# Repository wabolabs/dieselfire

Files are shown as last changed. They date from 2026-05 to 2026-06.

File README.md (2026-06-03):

# DieselFire

> **⚠ ALPHA QUALITY — NOT TESTED ON HARDWARE**
>
> This project is in early development. The firmware has **not** been tested on
> physical ESP32-S3 hardware. All protocol simulation and UI development has
> been done via the **PC simulator**. There are likely bugs, edge cases, and
> incomplete drivers. Use at your own risk. Hardware bringup is in progress.

A modernized open-source controller for generic Chinese diesel heaters, forked from [Afterburner](https://gitlab.com/mrjones.id.au/bluetoothheater) by Ray Jones.

## Overview

DieselFire is a complete redesign of the Afterburner project, updated with modern hardware while preserving the core functionality that made Afterburner popular:

- **Diesel heater control** via the "blue wire" half-duplex serial protocol (25000 baud)
- **WiFi connectivity** for web interface, MQTT, and OTA updates
- **Bluetooth Low Energy** for mobile app control
- **Environmental monitoring** with temperature, humidity, pressure, and CO detection
- **Color touchscreen UI** with LVGL graphics
- **Programmable timers** (14 channels)
- **Fuel gauge** and hour meter
- **Smart error detection**

## Online Simulator

Try the DieselFire UI in your browser without any hardware:
**[dieselfire.wabo.cc](https://dieselfire.wabo.cc)**

Runs as a WebAssembly build of the native PC simulator. Includes the full
touchscreen interface, Blue Wire protocol simulation, and a diesel heater
emulator for testing all states and fault conditions.

## Hardware

| Component | Specification |
|---|---|
| **MCU** | ESP32-S3-WROOM-1-N8R8 (8MB flash, 8MB PSRAM) |
| **Display** | 2.8" 320×240 ILI9341 TFT with capacitive touch (GT911) |
| **Ambient Sensor** | BME280 (temperature, humidity, pressure/altitude) |
| **CO Sensor** | MQ-7 carbon monoxide (external module) |
| **RTC** | DS3231 with CR2032 battery backup |
| **External Temp** | DS18B20 waterproof probe (optional) |
| **Power** | 12V DC input (heater system voltage) |
| **Connectivity** | USB-C (programming/debug), WiFi, BLE 5 |
| **Expansion** | 2× 2×10 GPIO headers |

## License

DieselFire is released under the **GNU General Public License v3.0**.

This project is a **fork** of [Afterburner](https://gitlab.com/mrjones.id.au/bluetoothheater) by Ray Jones (Copyright 2018-2020). The original Afterburner code was used as the foundation and has been substantially modified and modernized. All original Afterburner code remains under GPLv3 as per the original license.

See [LICENSE](LICENSE) for the full license text.

## Quick Start

1. **Hardware**: Order PCB from JLCPCB/PCBWay using Gerber files in `gerber/`
2. **Firmware**: Install PlatformIO, then run `pio run` to build
3. **Flash**: Connect via USB-C and run `pio run --target upload`
4. **Configure**: Connect to the AP "DieselFire" (password: thereisnospoon) or connect to existing WiFi

## Project Structure

```
DieselFire/
├── boards/                  # PlatformIO board definitions
├── docs/
│   ├── design/              # Design documents and specifications
│   ├── firmware/            # Firmware documentation
│   └── hardware/            # Hardware documentation
├── gerber/                  # PCB fabrication files
├── kicad/
│   ├── schematic/           # KiCad schematic files
│   ├── pcb/                 # KiCad PCB layout files
│   ├── footprints/          # Custom KiCad footprints
│   └── libraries/           # KiCad symbol libraries
├── lib/                     # PlatformIO libraries (vendored)
├── src/
│   ├── cfg/                 # Configuration headers
│   ├── Display/             # LVGL display driver and screens
│   ├── Protocol/            # Blue wire protocol handling
│   ├── RTC/                 # Real-time clock and timers
│   ├── Utility/             # Utility classes (sensors, storage, etc.)
│   ├── WiFi/                # WiFi, web server, OTA
│   ├── Bluetooth/           # BLE implementation
│   └── OLED/                # Legacy OLED code (to be removed)
├── platformio.ini           # PlatformIO project configuration
├── README.md
└── LICENSE
```

## Features

### Heater Control
- Power on/off commands
- Temperature setpoint adjustment
- Fuel mixture tuning
- Pump priming
- Thermostat mode (cyclic, stop/start, linear)
- Frost protection mode
- Humidity-based control
- OEM controller co-existence mode

### Connectivity
- **WiFi**: STA mode (connect to existing network) or AP mode (captive portal)
- **BLE 5**: Bluetooth Low Energy for mobile app control
- **MQTT**: Publish heater status and receive commands
- **Web Server**: HTTPS web interface with WebSocket JSON streaming
- **OTA**: Over-the-air firmware updates

### Sensors
- **BME280**: Ambient temperature, humidity, pressure (altitude)
- **MQ-7**: Carbon monoxide detection (external module)
- **DS18B20**: External waterproof temperature probe (optional)
- **SCD41**: CO2 sensing (optional, not on default board)

### User Interface
- **2.8" Color Touchscreen**: 320×240 ILI9341 with capacitive touch
- **LVGL Graphics**: Hardware-accelerated UI with PSRAM buffer
- **Menu System**: Hierarchical menus for all settings
- **Timer Chart**: Visual overview of 14 programmable timers
- **Status Display**: Real-time heater status, sensor readings, alerts

### Safety
- **CO Detection**: MQ-7 sensor with alarm LED
- **Low Voltage Cutout**: Auto-shutdown when battery voltage is too low
- **Error Detection**: Smart monitoring of heater state transitions
- **Watchdog**: Hardware and software watchdog for reliability

## Pinout

### ESP32-S3 GPIO Mapping

| Peripheral | GPIO | Interface | Notes |
|---|---|---|---|
| **Native USB** | IO19 (DP) / IO20 (DN) | USB 1.1 | USB-C, programming + debug |
| **SPI Display** | IO18 (MOSI) / IO17 (SCK) / IO16 (MISO) | SPI (HSPI) | ILI9341, 320×240 |
| **Display CS** | IO15 | GPIO | TFT chip select |
| **Display DC** | IO14 | GPIO | TFT data/command |
| **Display RST** | IO13 | GPIO | TFT reset |
| **Display BL** | IO12 | GPIO/PWM | TFT backlight |
| **Touch I2C** | IO21 (SDA) / IO10 (SCL) | I2C (GPIO) | GT911 capacitive touch |
| **Touch INT** | IO9 | GPIO | Touch interrupt |
| **Touch RST** | IO8 | GPIO | Touch reset |
| **Blue Wire UART** | IO43 (TX) / IO44 (RX) | UART0 @ 25kbps | Heater communication |
| **Tx Gate** | IO47 | GPIO | 74LCX125 control |
| **BME280 I2C** | IO21 (SDA) / IO22 (SCL) | I2C (VSPI) | Temp/RH/Pressure |
| **DS3231 I2C** | IO21 (SDA) / IO22 (SCL) | I2C (VSPI) | RTC |
| **DS18B20** | IO45 | OneWire | External temp probe |
| **MQ-7 AOUT** | IO4 | ADC1 (12-bit) | CO analog reading |
| **MQ-7 DOUT** | IO5 | GPIO input | CO digital alert |
| **Status LED** | IO48 | GPIO | Green, active-low |
| **CO Alarm LED** | IO44 | GPIO | Red, active-low |
| **Power Button** | IO0 | GPIO (input) | With pull-up |
| **Reset Button** | IO5 | GPIO | Standard boot button |

### Expansion Headers

**H1 (2×10):** GPIO33, GPIO34, GPIO35, GPIO36, GPIO37, GPIO38, GPIO39, GPIO40, 3.3V, GND, GND
**H2 (2×10):** GPIO41, GPIO42, GPIO43, GPIO44, GPIO45, GPIO46, GPIO47, GPIO48, 3.3V, GND, GND

### Connectors

| Connector | Type | Purpose |
|---|---|---|
| J1 | USB-C | Programming, debug, power |
| J2 | 2-pin terminal block (3.81mm) | 12V power input |
| J3 | 3-pin JST-XH (2.5mm) | Blue wire to heater |
| J4 | 3-pin JST-XH (2.5mm) | DS18B20 external temp sensor |
| J5 | 4-pin JST-XH (2.5mm) | MQ-7 CO sensor |
| H1, H2 | 2×10 header (2.54mm) | Expansion GPIO |

## Building

### Prerequisites

- [PlatformIO](https://platformio.org/) (latest version)
- ESP32-S3 compatible board (DieselFire PCB)
- USB-C cable

### Build Commands

```bash
# Install PlatformIO
pip install platformio

# Clone the repository
git clone https://github.com/wabolabs/DieselFire.git
cd DieselFire

# Build firmware
pio run

# Upload to board
pio run --target upload

# Monitor serial output
pio device monitor --baud 115200
```

### Board Definition

The DieselFire board is defined in `boards/dieselfire.json`. To use it:

```bash
pio run -e dieselfire
```

## Configuration

### WiFi Setup

On first boot, the device creates an access point:
- **SSID**: DieselFire
- **Password**: thereisnospoon

Connect to this AP and open a browser to `192.168.4.1` to configure WiFi.

### MQTT Setup

Configure MQTT settings in the web interface or via the debug console:
- Server address
- Port (1883 for MQTT, 8883 for MQTT over TLS)
- Client ID
- Username/Password (if required)
- Topic prefix

### Sensor Calibration

**MQ-7 CO Sensor:**
1. Power on the device in clean air (outdoors)
2. Wait 48-72 hours for the sensor to stabilize
3. Use the web interface to run calibration
4. The R0 value is stored in non-volatile memory

**DS18B20 Temperature Probe:**
1. Connect the probe to J4
2. The probe will be auto-detected on boot
3. Set offset in settings if needed

## Hardware Design

### PCB Specifications

- **Size**: 80mm × 60mm
- **Layers**: 2-layer
- **Trace width**: 0.2mm signal, 0.5mm power, 1mm 12V
- **Via size**: 0.3mm hole / 0.6mm pad
- **Clearance**: 0.15mm minimum

### BOM

| Reference | Part | Package | Qty | Est. Cost |
|---|---|---|---|---|
| U1 | ESP32-S3-WROOM-1-N8R8 | QFN-44 module | 1 | ~$4.00 |
| U2 | 2.8" ILI9341 TFT + FPC | FPC connector | 1 | ~$3.50 |
| U3 | GT911 | QFN-24 4×4 | 1 | ~$0.80 |
| U4 | BME280 | QFN-8 2×2 | 1 | ~$1.50 |
| U5 | MQ-7 | JST-XH 4-pin | 1 | ~$2.00 |
| U6 | DS18B20 | JST-XH 3-pin | 1 | ~$1.50 |
| U7 | DS3231 | SOIC-16 | 1 | ~$2.00 |
| U8 | 74LCX125 | SOIC-14 | 1 | ~$0.30 |
| U9×2 | BSS138 | SOT-23 | 2 | ~$0.10 |
| U10 | MP2451 | SOT-23-6 | 1 | ~$0.50 |
| U11 | AP2112 | SOT-89-3 | 1 | ~$0.20 |
| J1 | USB-C-S6 | SMD | 1 | ~$0.30 |
| J2 | Terminal Block 2×3.81 | TB | 1 | ~$0.20 |
| J3-J5 | JST-XH connectors | 2.5mm | 3 | ~$0.50 |
| BAT1 | CR2032 Holder | — | 1 | ~$0.50 |
| H1,H2 | 2×10 Header | 2.54mm | 2 | ~$0.20 |
| D1,D2 | LED 0603 | 0603 | 2 | ~$0.05 |
| SW1,SW2 | Tactile 6×6 | 6×6mm | 2 | ~$0.10 |
| Various | Resistors/Caps | 0402/0603 | ~20 | ~$1.00 |
| **Total BOM** | | | | **~$19.00** |

**PCB fabrication:** ~$5-10 for 5 boards (JLCPCB/PCBWay, 2-layer, 80×60mm)

## Firmware Development

### Architecture

The firmware follows a modular architecture:

```
┌─────────────────────────────────────────────────────────────┐
│                     DieselFire                                │
│                                                              │
│  ┌─────────────┐  ┌──────────────┐  ┌──────────────────┐   │
│  │  Display    │  │   UI Layer   │  │  Settings/Config │   │
│  │  (LVGL)     │  │  (Screens)   │  │  (NVS Storage)   │   │
│  └─────────────┘  └──────────────┘  └──────────────────┘   │
│                                                              │
│  ┌─────────────┐  ┌──────────────┐  ┌──────────────────┐   │
│  │  Protocol   │  │  Blue Wire   │  │  Sensor Layer    │   │
│  │  Handling   │  │  State Machine│ │  (BME280, MQ-7)  │   │
│  └─────────────┘  └──────────────┘  └──────────────────┘   │
│                                                              │
│  ┌─────────────┐  ┌──────────────┐  ┌──────────────────┐   │
│  │  WiFi/HTTP  │  │  BLE/Bluetooth│ │  MQTT/OTA        │   │
│  └─────────────┘  └──────────────┘  └──────────────────┘   │
│                                                              │
│  ┌──────────────────────────────────────────────────────┐   │
│  │                    ESP32-S3 Hardware                  │   │
│  └──────────────────────────────────────────────────────┘   │
└─────────────────────────────────────────────────────────────┘
```

### Key Modules

| Module | Description | Location |
|---|---|---|
| **Display** | LVGL integration, ILI9341 driver, GT911 touch | `src/Display/` |
| **Protocol** | Blue wire protocol, state machine, Tx management | `src/Protocol/` |
| **RTC** | Real-time clock, timers, timer manager | `src/RTC/` |
| **Utility** | Sensors, NV storage, JSON, GPIO helpers | `src/Utility/` |
| **WiFi** | WiFiManager, web server, OTA, MQTT | `src/WiFi/` |
| **Bluetooth** | BLE implementation | `src/Bluetooth/` |
| **OLED** | Legacy OLED screens (to be replaced by LVGL) | `src/OLED/` |

### Development Workflow

1. **Create a feature branch**
   ```bash
   git checkout -b feature/new-screen
   ```

2. **Make changes**
   - Add/modify code in `src/`
   - Update documentation in `docs/`

3. **Build and test**
   ```bash
   pio run
   pio run --target upload
   pio device monitor --baud 115200
   ```

4. **Commit and push**
   ```bash
   git add .
   git commit -m "Add new screen for timer overview"
   git push origin feature/new-screen
   ```

5. **Create a pull request**

## Troubleshooting

### Board Won't Flash

- Check USB-C cable (must be data-capable, not charge-only)
- Hold BOOT button while pressing RESET
- Check COM port in `platformio.ini`

### Display Not Working

- Verify FPC connector is seated correctly
- Check SPI pin connections
- Verify PSRAM is detected (check serial output)

### BME280 Not Detected

- Check I2C address (0x76 or 0x77)
- Verify pull-up resistors (4.7kΩ on SDA/SCL)
- Run I2C scanner from debug console

### MQ-7 Readings Unstable

- Ensure 48-72 hour warmup period
- Run calibration in clean air
- Check voltage divider (10kΩ + 10kΩ)
- Verify ADC pin (IO4) is correct

### Blue Wire Communication Issues

- Verify level shifter connections (BSS138)
- Check Tx gate control (IO47)
- Verify UART0 pins (IO43/IO44)
- Check heater blue wire is connected correctly

## Contributing

Contributions are welcome! Please:

1. Fork the repository
2. Create a feature branch
3. Make your changes
4. Submit a pull request

Please ensure your code follows the existing style and includes appropriate documentation.

## Acknowledgments

DieselFire is a fork of [Afterburner](https://gitlab.com/mrjones.id.au/bluetoothheater) by Ray Jones. The original Afterburner project was a groundbreaking open-source controller for Chinese diesel heaters, and this project builds upon that foundation.

Special thanks to:
- Ray Jones (Afterburner original author)
- James Clark (Afterburner co-author)
- The Afterburner community on GitLab
- The ESP32 and LVGL communities

## Disclaimer

DieselFire is provided "as is" without warranty of any kind. The authors are not responsible for any damage caused by the use of this software or hardware. Diesel heaters produce carbon monoxide and other hazardous gases. Always ensure proper ventilation and installation.

Use at your own risk.

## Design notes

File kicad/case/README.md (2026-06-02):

# DieselFire — 3D-Printable Enclosure

Parametric two-part enclosure for the 100 × 100 mm `DieselFire` PCB,
generated by [`generate_case.py`](generate_case.py) using CadQuery.

## Files

| File | Purpose |
|---|---|
| `dieselfire_case_base.stl` / `.step` | Bottom tray — holds the PCB on standoffs |
| `dieselfire_case_lid.stl` / `.step` | Top lid — screws down onto the base |
| `dieselfire_case_assembled.step` | Both parts mated, for preview/fit-check only |

Regenerate (and tweak any parameter) with:

```bash
cd kicad/case
python3 generate_case.py
```

## Key dimensions

| Parameter | Value |
|---|---|
| PCB | 100 × 100 × 1.6 mm |
| Outer envelope | 106 × 106 × 31.6 mm |
| Wall thickness | 2.4 mm |
| Floor / lid thickness | 2.0 mm |
| PCB standoff height | 10 mm (room for B.Cu connectors) |
| Clearance above PCB | 16 mm (display hangs from lid into here) |
| PCB-to-wall clearance | 0.6 mm per side |

## Display (ILI9341 2.8", lid-mounted)

The 2.8" panel mounts to the **inside of the lid**, facing the user; the PCB
sits behind it in the base. Its FPC tail folds down through the rib notch to the
FH12 connector (U11) on the board. The same geometry is mirrored on the board as
a documentation keepout in [`../pipeline.py`](../pipeline.py) (`DISP_*`).

| Feature | Value |
|---|---|
| Active-area window | 43.2 × 57.6 mm (portrait) |
| Glass pocket | 50 × 69.2 mm + 0.4 mm/side fit |
| Bezel ledge | front face stays proud of the glass |
| Retaining rib | 3.5 mm tall, 1.6 mm wall, with FPC exit notch on the +Y edge |

The glass drops into the pocket from the cavity side and seats against the bezel
ledge; the PCB behind it (on its standoffs) backs the panel. Add foam/VHB or
print the optional retention nubs if a tighter hold is needed.

## Buttons (side-actuated)

SW1/SW2 are right-angle tactile switches on the front board edge; their plungers
face the **front wall**, where two Ø7 mm access holes (`SIDE_BUTTONS`) let a cap
or finger reach them. This keeps the front face clear for the touchscreen.

## Mounting

- Four **M3 self-tapping screws** secure the PCB to the corner standoffs
  (pilot Ø2.6 mm) at board coordinates (5,5)/(95,5)/(5,95)/(95,95).
- Four **M3 screws** join the lid to the base through corner bosses
  (lid clearance Ø3.4 mm + Ø6 mm counterbore, base pilot Ø2.6 mm).

## Openings (aligned to measured connector positions)

| Wall | Connectors |
|---|---|
| Front (Y≈0) | J2 12 V terminal block, J4 DS18B20, J5 MQ-7, J1 USB-C |
| Left (X≈0) | J3 blue-wire to heater |
| Right (X≈100) | H1 / H2 expansion headers (ribbon slots) |
| Lid window | FH12 display-FPC + DS3231 coin cell access |

Floor and lid carry ventilation slots over the ESP32 / regulator area.

## Recommended print settings

| Setting | Value |
|---|---|
| Material | PETG (heat tolerant near a diesel heater) or PLA for bench use |
| Layer height | 0.2 mm |
| Walls / perimeters | 3 |
| Top/bottom layers | 4 |
| Infill | 20 % |
| Supports | None — both parts print flat, openings face sideways/up |
| Orientation | Base: floor down. Lid: top face down (window/bosses up). |

## Assumptions & caveats

- Connector cutouts are sized from PCB **courtyards**; the vertical connectors
  sit a few mm inset from the board edge, so the openings are cable-exit
  windows rather than tight panel-mount bezels. Verify against a printed
  first-article and adjust `CONNECTOR_CUTOUTS` in `generate_case.py` as needed.
- The ILI9341 display is assumed to be **panel-mounted externally** and fed by
  the FH12 FPC through the lid window. If you instead mount the display on the
  lid, replace `LID_WINDOW` with a recessed bezel + screw posts.
- All parameters live at the top of `generate_case.py`; nothing is hard-coded
  downstream.

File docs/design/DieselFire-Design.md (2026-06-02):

# DieselFire - Design Document

## Project Overview

DieselFire is a modernized controller for generic Chinese diesel heaters, forked from the original [DieselFire](https://dieselfire.wabo.cc) project. This document describes the complete hardware and firmware design.

## Block Diagram

```
┌─────────────────────────────────────────────────────────────────────┐
│                        DIESELFIRE                                │
│                                                                     │
│  ┌──────────┐    ┌──────────────┐    ┌──────────────────────────┐  │
│  │ 12V IN   │───▶│ MP2451 Buck  │───▶│ 5V Rail                  │  │
│  │ (J2)     │    │ 12V→5V       │    │                          │  │
│  └──────────┘    └──────────────┘    │  ┌────────────────────┐  │  │
│                                      │  │ AP2112 LDO         │  │  │
│                                      │  │ 5V→3.3V            │  │  │
│                                      │  └────────┬───────────┘  │  │
│                                      └───────────┼─────────────┘  │  │
│                                                  │                 │
│  ┌──────────┐    ┌──────────────┐    ┌───────────┼──────────┐    │  │
│  │ USB-C    │    │ ESP32-S3     │    │           │          │    │  │
│  │ (J1)     │───▶│ WROOM-1-N8R8 │    │  SPI      │  I2C     │    │  │
│  └──────────┘    │ (U1)         │    │           │          │    │  │
│                  │ 8MB Flash    │    │  ┌──────┐  │  ┌────┐  │    │  │
│                  │ 8MB PSRAM    │    │  │ILI93│  │  │BME │  │    │  │
│                  └──────┬───────┘    │  │ 41  │  │  │280 │  │    │  │
│                         │            │  └──────┘  │  └────┘  │    │  │
│                         │            │           │  │GT911 │  │    │  │
│                         │            │  ┌──────┐  │  └────┘  │    │  │
│                         │            │  │74LCX│  │  │DS3231│  │    │  │
│                         │            │  │125  │  │  └────┘  │    │  │
│                         │            │  └──┬──┘  └──────────┘    │  │
│                         │            │     │                     │  │
│                         │            │  BT│WIRE                 │  │
│                         │            │  UART                     │  │
│                         │            │     │                     │  │
│                         │            │  MQ-7                    │  │
│                         │            │  (J5)                    │  │
│                         │            │     │                     │  │
│                         │            │  DS18B20                 │  │
│                         │            │  (J4)                    │  │
│                         │            └──────────────────────────┘    │
└─────────────────────────────────────────────────────────────────────┘
```

## Power System

### Power Flow

```
12V IN (J2) ──┬───▶ MP2451 Buck ──▶ 5V Rail
                │
                └───▶ Reverse Polarity Protection (P-channel MOSFET)
                      │
                      └───▶ TVS Diode (SMAJ12A)
                              │
                              └───▶ Ferrite Bead (600Ω @ 100MHz)
                                      │
                                      └───▶ MP2451 VIN
```

### Regulators

| Regulator | Input | Output | Current | Package |
|---|---|---|---|---|
| MP2451 | 12V | 5V | 2A | SOT-23-6 |
| AP2112 | 5V | 3.3V | 1A | SOT-89-3 |

### Protection

- **Reverse Polarity:** P-channel MOSFET (SI2301)
- **Surge Protection:** TVS diode (SMAJ12A)
- **EMI Filtering:** Ferrite bead (600Ω @ 100MHz)
- **Decoupling:** 100µF + 0.1µF per rail

### Current Budget

| Component | Typical | Peak |
|---|---|---|
| ESP32-S3 (WiFi on) | 80-250mA | ~500mA |
| Display + backlight | 20-50mA | ~100mA |
| MQ-7 sensor | 15mA | 150mA (heating pulse) |
| Sensors (BME280, DS3231, GT911) | <5mA | <10mA |
| **Total** | **~150mA** | **~800mA** |

## Communication Interfaces

### Blue Wire (Heater Communication)

The "blue wire" is the half-duplex serial interface used by Chinese diesel heaters.

| Parameter | Value |
|---|---|
| Baud Rate | 25000 baud |
| Data Format | 8N1 |
| Logic Level | 5V (heater) / 3.3V (ESP32-S3) |
| Interface | UART0 (IO43/TX, IO44/RX) |

### Level Shifting

Bidirectional level shifting is required for the blue wire interface:

```
ESP32-S3 (3.3V) ──┬── BSS138 ──┬── Heater Blue Wire (5V)
                   │            │
                   └── BSS138 ──┘
```

### Tx Gate Control

A 74LCX125 buffer controls transmission to prevent feedback:

```
ESP32-S3 IO43 (TX) ──▶ 74LCX125 Input ──▶ BSS138 ──▶ Heater Blue Wire
                       │
ESP32-S3 IO47 (Tx Gate) ──▶ 74LCX125 Enable
```

### WiFi

- **Standard:** 802.11 b/g/n
- **Frequency:** 2.4 GHz
- **Modes:** STA (connect to existing network) or AP (captive portal)
- **Antenna:** Integrated on ESP32-S3 module

### Bluetooth

- **Standard:** BLE 5
- **Frequency:** 2.4 GHz
- **Profile:** Serial Port Profile (SPP) over BLE
- **Connection:** Mobile app or web interface

### USB

- **Type:** USB-C
- **Function:** Programming, debug, power
- **Protocol:** Native USB (no external USB-serial chip needed)
- **Baud Rate:** 115200 (debug console)

## Display Interface

### ILI9341 TFT Display

| Parameter | Value |
|---|---|
| Resolution | 320 × 240 pixels |
| Interface | SPI (4-wire) |
| Clock Speed | 40 MHz (write), 6 MHz (read) |
| Color Depth | 16-bit RGB565 |
| Backlight | LED (PWM controllable) |

### Pin Mapping

| Signal | ESP32-S3 GPIO | Notes |
|---|---|---|
| MOSI | IO18 | HSPI_MOSI |
| SCK | IO17 | HSPI_SCK |
| MISO | IO16 | HSPI_MISO (optional) |
| CS | IO15 | Chip select |
| DC | IO14 | Data/command select |
| RESET | IO13 | Display reset |
| BACKLIGHT | IO12 | PWM controlled |

### GT911 Capacitive Touch

| Signal | ESP32-S3 GPIO | Notes |
|---|---|---|
| SDA | IO21 | I2C data (shared bus) |
| SCL | IO10 | I2C clock |
| INT | IO9 | Touch interrupt |
| RST | IO8 | Touch reset |

### LVGL Graphics Library

| Parameter | Value |
|---|---|
| Version | 9.5.0 |
| Display Driver | esp_lcd (ILI9341) |
| Touch Driver | esp_lcd_touch_gt911 |
| Buffer Location | PSRAM (8MB) |
| Buffer Size | 320×240×2 bytes (153,600 bytes) |
| Double Buffering | Yes |
| DMA Support | Yes (SPI DMA) |

## Sensor Interface

### BME280 (Temperature, Humidity, Pressure)

| Parameter | Value |
|---|---|
| I2C Address | 0x76 (SDO → GND) |
| Temp Accuracy | ±1.0°C |
| Humidity Accuracy | ±3% RH |
| Pressure Accuracy | ±1 hPa |
| Interface | I2C (shared bus) |
| Sampling Mode | Forced |

### MQ-7 (Carbon Monoxide)

| Parameter | Value |
|---|---|
| Interface | Analog + Digital |
| AOUT | GPIO4 (ADC1, 12-bit) |
| DOUT | GPIO5 (GPIO input) |
| Power | 5V, ~75mA typical |
| Response Time | ~5 seconds |
| Voltage Divider | 10kΩ + 10kΩ (5V → 2.5V) |

### DS18B20 (External Temperature Probe)

| Parameter | Value |
|---|---|
| Interface | OneWire |
| GPIO | IO45 |
| Pull-up | 4.7kΩ |
| Accuracy | ±0.5°C |
| Range | -55°C to +125°C |
| Connector | JST-XH 3-pin |

### DS3231 (RTC)

| Parameter | Value |
|---|---|
| I2C Address | 0x68 |
| Interface | I2C (shared bus) |
| Battery | CR2032 |
| Accuracy | ±2 ppm (~1 minute/year) |
| Alarm | 1 per day |
| Connector | On-board (BAT1) |

## Connector Pinouts

### J1: USB-C

| Pin | Signal | Notes |
|---|---|---|
| A1, B12 | GND | Ground |
| A9, B10 | VBUS | 5V power |
| A7, B8 | CC1/CC2 | USB-C detection (5.1kΩ to GND) |
| A24, B17 | D+ | USB data + (IO19) |
| A25, B18 | D- | USB data - (IO20) |
| A17, B24 | SHIELD | Ground |

### J2: 12V Power Input (Terminal Block)

| Pin | Signal | Notes |
|---|---|---|
| 1 | 12V IN | Via reverse polarity protection |
| 2 | GND | Ground |

### J3: Blue Wire to Heater (JST-XH 3-pin)

| Pin | Signal | Notes |
|---|---|---|
| 1 | Blue Wire | Heater data line |
| 2 | 12V SENSE | Heater 12V sense |
| 3 | GND | Ground |

### J4: DS18B20 External Probe (JST-XH 3-pin)

| Pin | Signal | Notes |
|---|---|---|
| 1 | VCC | 3.3V |
| 2 | DATA | OneWire data (4.7kΩ pull-up) |
| 3 | GND | Ground |

### J5: MQ-7 CO Sensor (JST-XH 4-pin)

| Pin | Signal | Notes |
|---|---|---|
| 1 | VCC | 5V |
| 2 | GND | Ground |
| 3 | AOUT | Analog output (via voltage divider) |
| 4 | DOUT | Digital output |

### H1, H2: Expansion Headers (2×10, 2.54mm pitch)

**H1:**
| Pin | Signal | Pin | Signal |
|---|---|---|---|
| 1 | GPIO33 | 2 | GPIO34 |
| 3 | GPIO35 | 4 | GPIO36 |
| 5 | GPIO37 | 6 | GPIO38 |
| 7 | GPIO39 | 8 | GPIO40 |
| 9 | 3.3V | 10 | GND |
| 11 | GND | 12 | NC |
| 13 | NC | 14 | NC |
| 15 | NC | 16 | NC |
| 17 | NC | 18 | NC |
| 19 | NC | 20 | NC |

**H2:**
| Pin | Signal | Pin | Signal |
|---|---|---|---|
| 1 | GPIO41 | 2 | GPIO42 |
| 3 | GPIO43 | 4 | GPIO44 |
| 5 | GPIO45 | 6 | GPIO46 |
| 7 | GPIO47 | 8 | GPIO48 |
| 9 | 3.3V | 10 | GND |
| 11 | GND | 12 | NC |
| 13 | NC | 14 | NC |
| 15 | NC | 16 | NC |
| 17 | NC | 18 | NC |
| 19 | NC | 20 | NC |

## PCB Layout Guidelines

### Layer Stackup

| Layer | Description |
|---|---|
| Layer 1 (Top) | Signal traces, SMD components, silkscreen |
| Layer 2 (Bottom) | Ground plane, some signal traces, SMD components |

### Trace Widths

| Signal | Minimum Width | Notes |
|---|---|---|
| 12V Power | 1.0mm | Carries up to 2A |
| 5V Power | 0.5mm | Carries up to 1A |
| 3.3V Power | 0.3mm | Carries up to 500mA |
| Signal | 0.2mm | Standard signal traces |

### Via Requirements

| Parameter | Value |
|---|---|
| Hole Size | 0.3mm |
| Pad Size | 0.6mm |
| Clearance | 0.3mm |

### Clearance

| Parameter | Value |
|---|---|
| Minimum Clearance | 0.15mm |
| Minimum Copper-to-Copper | 0.2mm |
| Minimum Silkscreen-to-Copper | 0.2mm |

## Schematic Notes

### Power Rails

- **12V:** From J2 (terminal block), protected by reverse polarity circuit
- **5V:** From MP2451 buck converter, decoupled with 100µF + 0.1µF
- **3.3V:** From AP2112 LDO, decoupled with 10µF + 0.1µF

### I2C Bus

All I2C devices share the same bus (SDA: IO21, SCL: IO22):
- BME280 (0x76)
- GT911 touch (0x5D)
- DS3231 RTC (0x68)
- SCD41 CO2 (0x62, optional)

Pull-up resistors: 4.7kΩ on SDA and SCL to 3.3V.

### SPI Bus

The ILI9341 display uses HSPI:
- MOSI: IO18
- SCK: IO17
- MISO: IO16 (optional)
- CS: IO15
- DC: IO14
- RST: IO13
- BL: IO12

### UART for Blue Wire

UART0 is used for blue wire communication:
- TX: IO43
- RX: IO44
- Baud Rate: 25000
- Data Format: 8N1

Tx gate control via IO47 to 74LCX125 buffer.

### ADC

MQ-7 analog output connected to ADC1:
- Pin: IO4
- Resolution: 12-bit
- Attenuation: 11dB (0-3.3V range)
- Voltage Divider: 10kΩ + 10kΩ (5V → 2.5V)

### OneWire

DS18B20 external probe:
- Pin: IO45
- Pull-up: 4.7kΩ to 3.3V
- Protocol: Dallas OneWire

## Testing Points

| Test Point | Signal | Notes |
|---|---|---|
| TP1 | 3.3V | ESP32-S3 supply |
| TP2 | 5V | Buck converter output |
| TP3 | 12V | Power input |
| TP4 | GND | Ground |
| TP5 | IO43 | UART0 TX (blue wire) |
| TP6 | IO44 | UART0 RX (blue wire) |
| TP7 | IO18 | SPI MOSI (display) |
| TP8 | IO21 | I2C SDA (sensors) |
| TP9 | IO22 | I2C SCL (sensors) |

## Revision History

| Version | Date | Changes |
|---|---|---|
| 1.0 | 2024-01-01 | Initial design |

## References

- [ESP32-S3 Datasheet](https://www.espressif.com/sites/default/files/documentation/esp32-s3_datasheet_en.pdf)
- [ILI9341 Datasheet](https://www.adafruit.com/datasheets/ILI9341.pdf)
- [BME280 Datasheet](https://www.bosch-sensortec.com/media/boschsensortec/downloads/datasheets/bst-bme280-ds001.pdf)
- [MQ-7 Datasheet](https://www.sparkfun.com/datasheets/Sensors/MQ-7.pdf)
- [DS3231 Datasheet](https://datasheets.maximintegrated.com/en/ds/DS3231.pdf)
- [GT911 Datasheet](https://github.com/goodtft/GT911/blob/master/GT911_Datasheet.pdf)

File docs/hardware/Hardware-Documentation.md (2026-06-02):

# DieselFire - Hardware Documentation

## PCB Design

### Board Specifications

| Parameter | Value |
|---|---|
| Dimensions | 100mm × 100mm |
| Layers | 2-layer |
| Board Thickness | 1.6mm |
| Copper Weight | 1oz (35µm) |
| Surface Finish | HASL (Lead-free) |
| Silkscreen | White |
| Solder Mask | Green |

### Stackup

| Layer | Description |
|---|---|
| Layer 1 (Top) | Signal traces, SMD components, silkscreen |
| Layer 2 (Bottom) | Ground plane, some signal traces, SMD components |

### Design Rules

| Parameter | Value |
|---|---|
| Trace Width (Signal) | 0.2mm minimum |
| Trace Width (Power) | 0.5mm minimum |
| Trace Width (12V) | 1.0mm minimum |
| Via Hole Size | 0.3mm |
| Via Pad Size | 0.6mm |
| Clearance | 0.15mm minimum |
| Copper-to-Copper | 0.2mm minimum |
| Silkscreen-to-Copper | 0.2mm minimum |

## Schematic

The schematic is divided into the following sections:

### 1. Power Supply

- **Input:** 12V DC via terminal block (J2)
- **Protection:** Reverse polarity (P-channel MOSFET), TVS diode, ferrite bead
- **Regulation:** MP2451 buck (12V→5V), AP2112 LDO (5V→3.3V)
- **Decoupling:** 100µF + 0.1µF per rail

### 2. Microcontroller

- **MCU:** ESP32-S3-WROOM-1-N8R8 (U1)
- **Flash:** 8MB
- **PSRAM:** 8MB
- **USB:** Native USB-C (IO19/IO20)

### 3. Display

- **TFT:** 2.8" ILI9341, 320×240 (FPC into U11, an FH12-18S 0.5mm connector)
- **Touch:** GT911 capacitive (U10, on the main board)
- **Interface:** SPI (IO16-18), I2C (IO10, IO21)
- **Mounting:** The bare panel mounts to the **inside of the case lid** facing
  the user (active area 43.2 × 57.6 mm portrait, glass 50 × 69.2 mm). The PCB
  sits behind it; the FPC tail folds down to U11. A documentation keepout for
  the panel is drawn on the board's `Dwgs.User` layer (see `DISP_*` in
  `kicad/pipeline.py`) so no tall part lands under the display.

### 3a. User Buttons

- **SW1/SW2:** right-angle (side-actuated) tactile switches on the front board
  edge; plungers face the front wall so they're pressed from the **side of the
  case**, keeping the front face clear for the touchscreen.

### 4. Sensors

- **BME280:** Temperature, humidity, pressure (U4)
- **DS3231:** RTC with battery backup (U7)
- **MQ-7:** CO sensor (external via J5)
- **DS18B20:** External temp probe (external via J4)

### 5. Blue Wire Interface

- **UART:** UART0 @ 25kbps (IO43/IO44)
- **Level Shifting:** BSS138 ×2 (U8)
- **Tx Gate:** 74LCX125 (U6)

### 6. Expansion

- **Headers:** H1, H2 (2×10, 2.54mm pitch)
- **GPIO:** 16 available GPIO pins

## PCB Layout

### Component Placement

```
┌──────────────────────────────────────────────────────────────┐
│  TOP VIEW (80mm × 60mm)                                      │
│                                                              │
│  ┌────────────┐  ┌──────────────────────────────────────┐   │
│  │  J2        │  │  J1 (USB-C)                          │   │
│  │  12V IN    │  │                                      │   │
│  └────────────┘  └──────────────────────────────────────┘   │
│                                                              │
│  ┌──────────────┐  ┌────────────────────────────────────┐   │
│  │  U10 AP2112  │  │  U1 ESP32-S3                       │   │
│  │  5V→3.3V LDO │  │  (center, large QFN)               │   │
│  └──────────────┘  └────────────┬───────────────────────┘   │
│                                 │                            │
│  ┌──────────────┐  ┌────────────┴───────────────────────┐   │
│  │  U9 MP2451   │  │  U2 TFT Display (FPC connector)    │   │
│  │  12V→5V Buck │  │  (top edge, above ESP32-S3)        │   │
│  └──────────────┘  └────────────────────────────────────┘   │
│                                                              │
│  ┌──────────┐  ┌──────────────────────────────────────┐    │
│  │  U4      │  │  J3 (Blue Wire)                      │    │
│  │  BME280  │  │  (right edge)                        │    │
│  └──────────┘  └──────────────────────────────────────┘    │
│                                                              │
│  ┌──────────┐  ┌──────────────────────────────────────┐    │
│  │  U7      │  │  J4 (DS18B20)                        │    │
│  │  DS3231  │  │  (bottom edge)                       │    │
│  └──────────┘  └──────────────────────────────────────┘    │
│                                                              │
│  ┌──────────┐  ┌──────────────────────────────────────┐    │
│  │  U8×2    │  │  J5 (MQ-7)                           │    │
│  │  BSS138  │  │  (bottom-right)                      │    │
│  └──────────┘  └──────────────────────────────────────┘    │
│                                                              │
│  ┌──────────┐  ┌──────────────────────────────────────┐    │
│  │  U6      │  │  H1,H2 + SW1,SW2, D1,D2             │    │
│  │  74LCX125│  │  (bottom-left)                       │    │
│  └──────────┘  └──────────────────────────────────────┘    │
│                                                              │
│  ┌──────────────────────────────────────────────────────┐   │
│  │  BAT1 (CR2032)                                       │   │
│  │  (corner, near edge)                                 │   │
│  └──────────────────────────────────────────────────────┘   │
└──────────────────────────────────────────────────────────────┘
```

### Key Layout Considerations

1. **Antenna Clearance:** Keep ground pour away from top edge (ESP32-S3 antenna)
2. **Power Traces:** 12V and 5V traces should be wide (≥1mm)
3. **SPI Traces:** Keep display SPI traces short (≤50mm)
4. **Blue Wire Traces:** Shield UART traces from noise
5. **MQ-7 Power:** Separate 5V rail for MQ-7 to avoid noise
6. **I2C Pull-ups:** 4.7kΩ on SDA and SCL

## Assembly

### BOM (Bill of Materials)

| Reference | Part | Package | Qty | Est. Cost |
|---|---|---|---|---|
| U1 | ESP32-S3-WROOM-1-N8R8 | QFN-44 module | 1 | ~$4.00 |
| U2 | 2.8" ILI9341 TFT + FPC | FPC connector | 1 | ~$3.50 |
| U3 | GT911 | QFN-24 4×4 | 1 | ~$0.80 |
| U4 | BME280 | QFN-8 2×2 | 1 | ~$1.50 |
| U5 | MQ-7 | JST-XH 4-pin | 1 | ~$2.00 |
| U6 | DS18B20 | JST-XH 3-pin | 1 | ~$1.50 |
| U7 | DS3231 | SOIC-16 | 1 | ~$2.00 |
| U8 | 74LCX125 | SOIC-14 | 1 | ~$0.30 |
| U9×2 | BSS138 | SOT-23 | 2 | ~$0.10 |
| U10 | MP2451 | SOT-23-6 | 1 | ~$0.50 |
| U11 | AP2112 | SOT-89-3 | 1 | ~$0.20 |
| J1 | USB-C-S6 | SMD | 1 | ~$0.30 |
| J2 | Terminal Block 2×3.81 | TB | 1 | ~$0.20 |
| J3-J5 | JST-XH connectors | 2.5mm | 3 | ~$0.50 |
| BAT1 | CR2032 Holder | — | 1 | ~$0.50 |
| H1,H2 | 2×10 Header | 2.54mm | 2 | ~$0.20 |
| D1,D2 | LED 0603 | 0603 | 2 | ~$0.05 |
| SW1,SW2 | Tactile 6×6 | 6×6mm | 2 | ~$0.10 |
| Various | Resistors/Caps | 0402/0603 | ~20 | ~$1.00 |
| **Total BOM** | | | | **~$19.00** |

**PCB fabrication:** ~$5-10 for 5 boards (JLCPCB/PCBWay, 2-layer, 80×60mm)

### Assembly Order

1. **Solder small SMD components first** (resistors, capacitors, LEDs)
2. **Solder ICs** (BSS138, MP2451, AP2112, 74LCX125, BME280, GT911, DS3231)
3. **Solder ESP32-S3 module** (U1) - use reflow oven or hot air
4. **Solder USB-C connector** (J1)
5. **Solder terminal block** (J2)
6. **Solder JST-XH connectors** (J3-J5)
7. **Solder headers** (H1, H2)
8. **Install CR2032 battery** (BAT1)
9. **Install TFT display** (U2) - slide into FPC connector
10. **Test and debug**

### Testing Checklist

- [ ] Measure 12V input at J2
- [ ] Measure 5V at MP2451 output
- [ ] Measure 3.3V at AP2112 output
- [ ] Check for short circuits between 3.3V and GND
- [ ] Check for short circuits between 5V and GND
- [ ] Check for short circuits between 12V and GND
- [ ] Verify USB-C connection (D+/D-)
- [ ] Verify I2C bus (SDA/SCL pull-ups)
- [ ] Verify SPI bus (MOSI/SCK/MISO)
- [ ] Verify UART0 (TX/RX)
- [ ] Flash firmware and test

## Fabrication

### Gerber Files

Generate Gerber files from KiCad:
1. Open schematic in KiCad
2. Update PCB from schematic
3. Go to File → Plot → Gerber Files
4. Select all layers
5. Plot
6. Zip the output files

### Order from JLCPCB/PCBWay

1. Upload Gerber files
2. Select specifications:
   - Layers: 2
   - Board size: 80×60mm
   - Thickness: 1.6mm
   - Copper weight: 1oz
   - Surface finish: HASL (Lead-free)
   - Silkscreen: White
   - Solder mask: Green
3. Select assembly (optional)
4. Submit order

### Assembly Service (Optional)

JLCPCB and PCBWay offer assembly services:
1. Upload Gerber files
2. Upload BOM file
3. Upload pick-and-place file
4. Select components
5. Submit order

## Maintenance

### Battery Replacement

CR2032 battery (BAT1) should be replaced every 2-3 years:
1. Remove old battery from holder
2. Insert new CR2032 battery (positive side up)
3. Verify RTC is keeping time

### Sensor Replacement

**BME280:**
- Soldered QFN-8 package
- Replace with hot air rework station

**GT911:**
- Soldered QFN-24 package
- Replace with hot air rework station

**MQ-7:**
- External module (JST-XH connector)
- Simply unplug and replace

**DS18B20:**
- External probe (JST-XH connector)
- Simply unplug and replace

## Revision History

| Version | Date | Changes |
|---|---|---|
| 1.0 | 2024-01-01 | Initial design |

## References

- [KiCad Documentation](https://kicad.org/docs/)
- [JLCPCB Assembly Guide](https://support.jlcpcb.com/article/26-how-to-prepare-the-bom-and-place-files)
- [PCBWay Assembly Guide](https://www.pcbway.com/blog/technology/How_to_prepare_BOM_and_Pick_and_Place_files_for_PCB_assembly.html)

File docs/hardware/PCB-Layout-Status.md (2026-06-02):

# DieselFire - PCB Layout Status

## Current State

The PCB is generated end-to-end by the automation pipeline
[`kicad/pipeline.py`](../../kicad/pipeline.py) (place → Freerouting autoroute →
GND pour → DRC → fab export). Run it with:

```bash
kicad/run_pipeline.sh --full      # or: python3 kicad/pipeline.py
```

### Completed (automated)

- **Board outline**: 100 × 100 mm, 1.6 mm, 2-layer, M3 mounting holes at the
  four corners (5,5)/(95,5)/(5,95)/(95,95).
- **Placement**: all 44 footprints placed from KiCad's built-in libraries.
- **Routing**: ~348 trace segments + routing vias via Freerouting.
- **Ground**: GND zones on both layers + ~371 stitching vias (grid + per-pad).
- **Display keepout**: the lid-mounted ILI9341 panel outline (50 × 69.2 mm) and
  active area (43.2 × 57.6 mm) are drawn on `Dwgs.User` with a label, so no tall
  part lands under the display. Driven by the `DISP_*` constants.
- **Side buttons**: SW1/SW2 are right-angle (side-actuated) tactile switches on
  the front edge; the case provides plunger holes.
- **Fab output**: gerbers, Excellon drill, and pick-and-place CSV in
  `kicad/fabrication/`.

### One manual step: fill the GND zones

The headless `pcbnew` used by CI/sandbox runs may lack a program context, in
which case `ZONE_FILLER` is unavailable and the pipeline saves the GND zones
**defined but unfilled** (it auto-detects this via a runtime probe). When that
happens, kicad-cli DRC reports the GND pads/vias as unconnected.

**To finish:** open `kicad/pcb/DieselFire.kicad_pcb` in KiCad and press
**B** (Edit ▸ Fill All Zones). This pours the planes and clears all GND
unconnected/dangling-via items, leaving only the two cosmetic silk-overlap
warnings on U8. In a full KiCad install the pipeline fills the zones
automatically and the saved board is already clean.

## Display & button mechanics

- The 2.8" ILI9341 panel mounts to the **inside of the case lid**, facing the
  user; the PCB sits behind it in the base. The FPC tail folds down to U11.
- Buttons are pressed from the **side of the case** through plunger holes, so
  the front face stays clear for the touchscreen.

See [`kicad/case/README.md`](../../kicad/case/README.md) for the enclosure and
[DieselFire-Design.md](../design/DieselFire-Design.md) for the schematic.

## Next steps

1. Open the PCB in KiCad and **Fill All Zones** (if generated headless).
2. Review the two silk-overlap warnings on U8 (cosmetic).
3. Regenerate gerbers (`kicad-cli` or the pipeline) and order from JLCPCB/PCBWay.

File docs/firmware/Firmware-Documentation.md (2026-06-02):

# DieselFire - Firmware Documentation

## Architecture Overview

DieselFire firmware is built on the ESP32-S3 with ESP-IDF v5.x framework. The architecture follows a modular design with clear separation of concerns.

### High-Level Architecture

```
┌─────────────────────────────────────────────────────────────┐
│                     DieselFire                            │
│                                                              │
│  ┌─────────────┐  ┌──────────────┐  ┌──────────────────┐   │
│  │  Display    │  │   UI Layer   │  │  Settings/Config │   │
│  │  (LVGL)     │  │  (Screens)   │  │  (NVS Storage)   │   │
│  └─────────────┘  └──────────────┘  └──────────────────┘   │
│                                                              │
│  ┌─────────────┐  ┌──────────────┐  ┌──────────────────┐   │
│  │  Protocol   │  │  Blue Wire   │  │  Sensor Layer    │   │
│  │  Handling   │  │  State Machine│ │  (BME280, MQ-7)  │   │
│  └─────────────┘  └──────────────┘  └──────────────────┘   │
│                                                              │
│  ┌─────────────┐  ┌──────────────┐  ┌──────────────────┐   │
│  │  WiFi/HTTP  │  │  BLE/Bluetooth│ │  MQTT/OTA        │   │
│  └─────────────┘  └──────────────┘  └──────────────────┘   │
│                                                              │
│  ┌──────────────────────────────────────────────────────┐   │
│  │                    ESP32-S3 Hardware                  │   │
│  └──────────────────────────────────────────────────────┘   │
└─────────────────────────────────────────────────────────────┘
```

## Module Description

### Display Module (`src/Display/`)

Handles LVGL integration, display driver, and touch input.

**Key Files:**
- `LVGLDisplay.cpp/.h` - LVGL initialization and display management
- `IL9341Driver.cpp/.h` - ILI9341 SPI display driver
- `GT911Touch.cpp/.h` - GT911 capacitive touch driver
- `LVGLScreens/` - Individual screen implementations

**Initialization:**
```cpp
// In LVGLDisplay::begin()
lv_init();
lv_display_t* disp = lvgl_port_init();
lv_indev_t* touch = lvgl_port_add_touch();
```

### Protocol Module (`src/Protocol/`)

Handles blue wire communication with the diesel heater.

**Key Files:**
- `Protocol.cpp/.h` - Protocol frame handling
- `TxManage.cpp/.h` - Transmission management
- `BlueWireTask.cpp/.h` - Blue wire state machine task
- `SmartError.cpp/.h` - Error detection and handling

**Blue Wire State Machine:**
1. **Idle** - Wait for heater activity
2. **OEMCtrlRx** - Receive OEM controller frame (if present)
3. **HeaterRx1** - Receive heater response to OEM
4. **TxStart** - Start transmission
5. **TxInterval** - Transmit data
6. **HeaterRx2** - Receive heater response to BTC
7. **ExchangeComplete** - Complete exchange

### RTC Module (`src/RTC/`)

Handles real-time clock and timer management.

**Key Files:**
- `Clock.cpp/.h` - DS3231 RTC driver
- `Timers.cpp/.h` - Timer management
- `TimerManager.cpp/.h` - Timer scheduling
- `RTCStore.cpp/.h` - RTC data storage

### Utility Module (`src/Utility/`)

General utility classes for sensors, storage, and helpers.

**Key Files:**
- `TempSense.cpp/.h` - Temperature sensor abstraction (BME280 + DS18B20)
- `MQCOSensor.cpp/.h` - MQ-7 CO sensor driver
- `NVStorage.cpp/.h` - Non-volatile storage
- `BTC_JSON.cpp/.h` - JSON data handling
- `FuelGauge.cpp/.h` - Fuel consumption tracking
- `HourMeter.cpp/.h` - Run time and glow time tracking

### WiFi Module (`src/WiFi/`)

Handles WiFi connectivity, web server, and OTA updates.

**Key Files:**
- `BTCWifi.cpp/.h` - WiFi connection management
- `BTCWebServer.cpp/.h` - Web server with WebSocket
- `BTCota.cpp/.h` - OTA update handling
- `ABMQTT.cpp/.h` - MQTT client

### Bluetooth Module (`src/Bluetooth/`)

Handles BLE communication for mobile app control.

**Key Files:**
- `BluetoothESP32.cpp/.h` - ESP32 native BLE implementation
- `BluetoothAbstract.cpp/.h` - Abstract Bluetooth interface

### OLED Module (`src/OLED/`)

Legacy OLED screens (to be replaced by LVGL).

**Note:** This module is being phased out. New screens should use LVGL.

## Build Configuration

### PlatformIO Setup

**platformio.ini:**
```ini
[env:dieselfire]
platform = espressif32@6.12.0
board = dieselfire
framework = espidf
board_build.partitions = default_8MB.csv
build_flags =
    -DBOARD_HAS_PSRAM
    -DHTTPS_LOGLEVEL=2
    -DCORE_DEBUG_LEVEL=5
lib_deps =
    lvgl/lvgl@^9.5.0
    espressif/esp_lcd@^2.0.0
    espressif/esp_lvgl_port@^2.0.0
    espressif/esp_lcd_touch_gt911@^1.2.0
    adafruit/Adafruit BME280 Library@^2.3.0
    adafruit/RTClib@^2.1.3
    arduinojson/ArduinoJson@^7.2.0
    wmaz/WiFiManager@^2.0.17
    marvinroger/async-mqtt-client@^0.9.0
upload_speed = 921600
monitor_speed = 115200
```

### Board Definition

**boards/dieselfire.json:**
```json
{
  "build": {
    "core": "esp32",
    "cpu": "esp32s3",
    "f_cpu": "240000000L",
    "f_flash": "80000000L",
    "flash_mode": "qio",
    "mcu": "esp32s3",
    "variant": "esp32s3",
    "partitions": "default_8MB.csv",
    "extra_inc": "sdkconfig.h"
  },
  "connectivity": ["wifi", "bluetooth"],
  "debug": {
    "openocd_target": "esp32s3.cfg"
  },
  "frameworks": ["arduino", "espidf"],
  "name": "DieselFire",
  "upload": {
    "flash_size": "8MB",
    "max_ram_size": "327680",
    "max_size": 8388608,
    "require_upload_port": true,
    "speed": 921600
  },
  "url": "https://github.com/yourusername/DieselFire",
  "vendor": "DieselFire"
}
```

## Sensor Calibration

### MQ-7 CO Sensor

**Calibration Procedure:**
1. Power on device in clean air (outdoors)
2. Wait 48-72 hours for sensor stabilization
3. Run calibration routine via web interface or debug console
4. R0 value is stored in NVS

**Calibration Code:**
```cpp
// In MQCOSensor::calibrate()
float rs = readRs();  // Read sensor resistance
R0 = rs / pow(PPM / a, 1.0 / b);  // Calculate R0
saveR0ToNVS();  // Store in non-volatile storage
```

### DS18B20 Temperature Probe

**Offset Calibration:**
1. Compare reading with known accurate thermometer
2. Set offset in settings: `TempSensor.setOffset(idx, offset)`
3. Offset is stored in NVS

## Debugging

### Serial Console

Access via USB-C at 115200 baud:
```bash
pio device monitor --baud 115200
```

**Debug Commands:**
- `+` - Request heater ON
- `-` - Request heater OFF
- `r` - Reboot device
- `s` - Show sensor readings
- `m` - Configure MQTT
- `j` - Toggle JSON reporting

### I2C Scanner

Scan I2C bus for connected devices:
```cpp
// In debug console
i2c_scan
```

Expected output:
```
I2C Scanner:
  Address: 0x76 - BME280
  Address: 0x5D - GT911
  Address: 0x68 - DS3231
```

### LVGL Debug

Enable LVGL debug output:
```cpp
// In platformio.ini
build_flags =
    -DLV_LOG_LEVEL=LV_LOG_LEVEL_TRACE
    -DLV_LOG_PRINTF=1
```

## OTA Update

### Over-the-Air Firmware Updates

**Via Web Interface:**
1. Connect to device via WiFi
2. Navigate to Settings → Firmware Update
3. Upload .bin file
4. Device reboots with new firmware

**Via Serial:**
```bash
pio run --target upload
```

**Via OTA:**
```bash
pio run --target upload --upload-port 192.168.1.100
```

## Memory Layout

### Flash Partition

For 8MB flash:
```
# Name,   Type, SubType, Offset,    Size, Flags
nvs,      data, nvs,     0x9000,    0x5000,
otadata,  data, ota,     0xe000,    0x2000,
app0,     app,  ota_0,   0x10000,   0x1E0000,
app1,     app,  ota_1,   0x1F0000,  0x1E0000,
spiffs,   data, spiffs,  0x3D0000,  0x30000,
coredump, data, coredump,0x6D0000,  0x10000,
fat,      data, fat,     0x6E0000,  0x720000,
```

### PSRAM Usage

| Component | Size | Notes |
|---|---|---|
| LVGL Display Buffer | 153,600 bytes | 320×240×2 (double buffered) |
| LVGL Font Cache | 32,768 bytes | Cached font glyphs |
| LVGL Widget Objects | 65,536 bytes | Screen widgets and elements |
| WebSocket Buffers | 32,768 bytes | JSON data buffering |
| **Total** | **~284,672 bytes** | Well within 8MB PSRAM |

## Task Priorities

| Task | Priority | Stack Size | Notes |
|---|---|---|---|
| Blue Wire Task | 4 | 4096 bytes | Highest priority, real-time |
| Arduino Loop | 3 | 2048 bytes | Main application loop |
| LVGL Task | 2 | 2048 bytes | Display updates |
| WiFi Task | 1 | 4096 bytes | WiFi management |
| MQTT Task | 1 | 2048 bytes | MQTT communication |
| Watchdog Task | 5 | 1024 bytes | Highest priority, watchdog |

## Error Handling

### Watchdog

Hardware watchdog (TWDT) is enabled:
```cpp
// In setup()
esp_task_wdt_init(TWDT_TIMEOUT_S, true);
esp_task_wdt_add(NULL);
```

### Brownout Detector

Brownout detector is enabled:
```cpp
// In setup()
esp_pm_config_t pm_config = {
    .max_freq_mhz = 240,
    .min_freq_mhz = 40,
    .light_sleep_enable = true
};
esp_pm_configure(&pm_config);
```

### NVS Error Handling

Non-volatile storage errors are handled gracefully:
```cpp
// In NVStorage::init()
nvs_handle_t handle;
esp_err_t err = nvs_open("storage", NVS_READWRITE, &handle);
if (err != ESP_OK) {
    // Handle error, possibly erase NVS
    nvs_flash_erase();
    nvs_flash_init();
}
```

## Contributing to Firmware

### Adding a New Screen

1. Create new file in `src/Display/LVGLScreens/`
2. Implement `CLVGLScreen` base class
3. Add to screen manager
4. Register in menu system

### Adding a New Sensor

1. Create new driver in `src/Utility/`
2. Implement `ISensor` interface
3. Add to sensor manager
4. Update NVS storage if needed

### Testing

Run tests with:
```bash
pio test --environment dieselfire
```

## References

- [ESP-IDF Documentation](https://docs.espressif.com/projects/esp-idf/en/latest/esp32s3/)
- [LVGL Documentation](https://docs.lvgl.io/)
- [PlatformIO Documentation](https://docs.platformio.org/)
- [DieselFire Documentation](https://dieselfire.wabo.cc/-/wikis/home)

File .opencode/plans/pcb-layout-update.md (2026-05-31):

# PCB Layout Update - Plan

## Overview
Update `plan.py` OVERRIDES to match the manually-adjusted test file layout, which has better spacing and component distribution. Then re-run the placement and autorouting pipeline.

## Changes to `plan.py` (OVERRIDES)

### Moved Components (from plan to test positions)

| Component | Old Position | New Position | Reason |
|---|---|---|---|
| U1 (ESP32) | (38, 28) | (37, 19) | Moved down for better spacing |
| U11 (Display) | (40, 48) | (48, 39) | Moved right/down, closer to board center |
| U2 (MP2451) | (32, 34) | (29, 30) | Moved down-left |
| U7 (DS3231) | (70, 50) | (53, 21) | Moved from top-right to center |
| BAT1 (CR2032) | (70, 50) | (19, 54) | Moved from top-right to top-left |
| J1 (USB-C) | (72, 6) | (74, 7) | Slight adjustment |
| J2 (Terminal) | (8, 6) | (9, 22) | Moved up along edge |
| J3 (Heater) | (8, 14) | (7, 30) | Moved up |
| J4 (DS18B20) | (66, 6) | (36, 6) | Moved to bottom-center, clear C9 |
| J5 (MQ-7) | (74, 6) | (47, 8) | Moved left to bottom-center |
| H1 (Header 1) | (66, 16) | (72, 18) | Adjusted |
| H2 (Header 2) | (66, 30) | (62, 18) | Adjusted |
| U8_1 (BSS138 TX) | (8, 44) | (8.4, 40) | Adjusted |
| U8_2 (BSS138 RX) | (12, 44) | (14.4, 40) | Adjusted |
| SW1 (Power) | (34, 34) | (10, 23) | **Left edge** - power button |
| SW2 (Reset) | (46, 34) | (16, 23) | **Left edge** - reset button |

### New Overrides (added to OVERRIDES)

| Component | Position | Reason |
|---|---|---|
| C10 | (43, 10) | Moved from decoup zone to clear J4 |

### Updated Exclusion Sizes

| Component | Old Half-Size | New Half-Size | Reason |
|---|---|---|---|
| U1 | (4.0, 6.0) | (4.0, 6.0) | No change |
| U11 | (8.0, 6.0) | (8.0, 6.0) | No change |
| U7 | (3.0, 3.0) | (3.0, 3.0) | No change |
| BAT1 | (4.0, 4.0) | (4.0, 4.0) | No change |

## Changes to `apply.py` (zone_map)

Remove C10 from automatic zone placement:
```python
# In determine_zone(), add:
"C10": "decoup",  # explicit zone assignment
```

## Changes to `critical.py` (BUTTON routes)

Update BUTTON1 and BUTTON2 route coordinates to match new switch positions:

```python
# BUTTON1: U1 (37, 19) → SW1 (10, 23)
routes.append(Route("POWER_BTN", "BUTTON1", width=0.2))
routes[-1].add(37, 19).add(25, 22).add(10, 23)

# BUTTON2: U1 (37, 19) → SW2 (16, 23)
routes.append(Route("RESET_BTN", "BUTTON2", width=0.2))
routes[-1].add(37, 19).add(28, 22).add(16, 23)
```

## Execution Order

1. Copy test file → working PCB:
   ```bash
   cp kicad/pcb/Afterburner-Modern-test.kicad_pcb kicad/pcb/Afterburner-Modern.kicad_pcb
   cp kicad/pcb/Afterburner-Modern-test.kicad_prl kicad/pcb/Afterburner-Modern.kicad_prl
   cp kicad/pcb/Afterburner-Modern-test.kicad_pro kicad/pcb/Afterburner-Modern.kicad_pro
   ```

2. Update plan.py with new positions (create new OVERRIDES)

3. Update apply.py zone_map for C10

4. Update critical.py BUTTON routes

5. Run pipeline:
   ```bash
   python3 kicad/pcb_placement/apply.py
   python3 kicad/pcb_routing/critical.py
   python3 kicad/pcb_routing/autoroute.py
   ```

## Verification Checklist

- [ ] All 46 footprints placed on-board (no off-board components)
- [ ] No overlaps between components (< 3mm clearance)
- [ ] J4 (36, 6) has > 2mm clearance from C9 (34, 10)
- [ ] C10 (43, 10) has > 2mm clearance from J4 and J5
- [ ] SW1 (10, 23) and SW2 (16, 23) are on left edge with 6mm spacing
- [ ] DRC passes with 0 violations
- [ ] All nets connected (or connected via GND pours)
- [ ] Fabrication files exported

## Expected Route Lengths

| Route | Plan Length | Test Length | Δ |
|---|---|---|---|
| 12V: J2→U2 | 36.9mm | 21.6mm | -15.3mm ✓ |
| 5V: U2→U3 | 8.0mm | 12.4mm | +4.4mm |
| 3V3: U3→U1 | 15.2mm | 23.6mm | +8.3mm |
| USB: J1→U1 | 40.5mm | 38.7mm | -1.8mm ✓ |
| SPI: U1→U11 | 20.1mm | 22.3mm | +2.2mm |
| I2C: U1→U10 | 26.8mm | 35.4mm | +8.6mm |
| BlueTX: U1→J3 | 33.1mm | 32.0mm | -1.1mm ✓ |
| TEMP: U1→J4 | 35.6mm | 11.2mm | -24.4mm ✓✓ |
| CO: U1→J5 | 42.2mm | 14.6mm | -27.6mm ✓✓ |
| BUTTON1: U1→SW1 | 19.6mm | ~28mm | (new) |
| BUTTON2: U1→SW2 | 19.6mm | ~23mm | (new) |

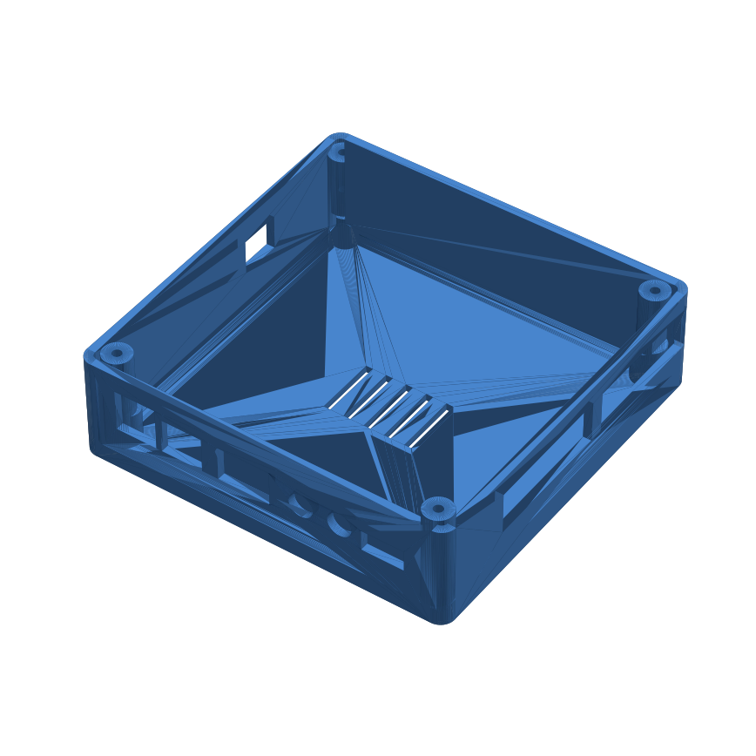
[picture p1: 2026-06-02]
renders/case_base.png

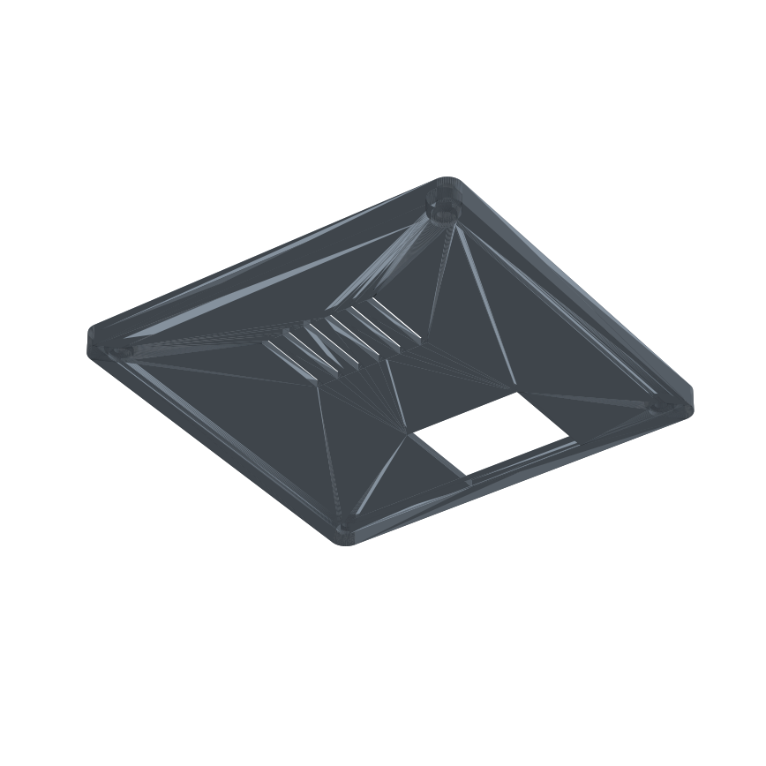
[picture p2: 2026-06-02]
renders/case_lid.png

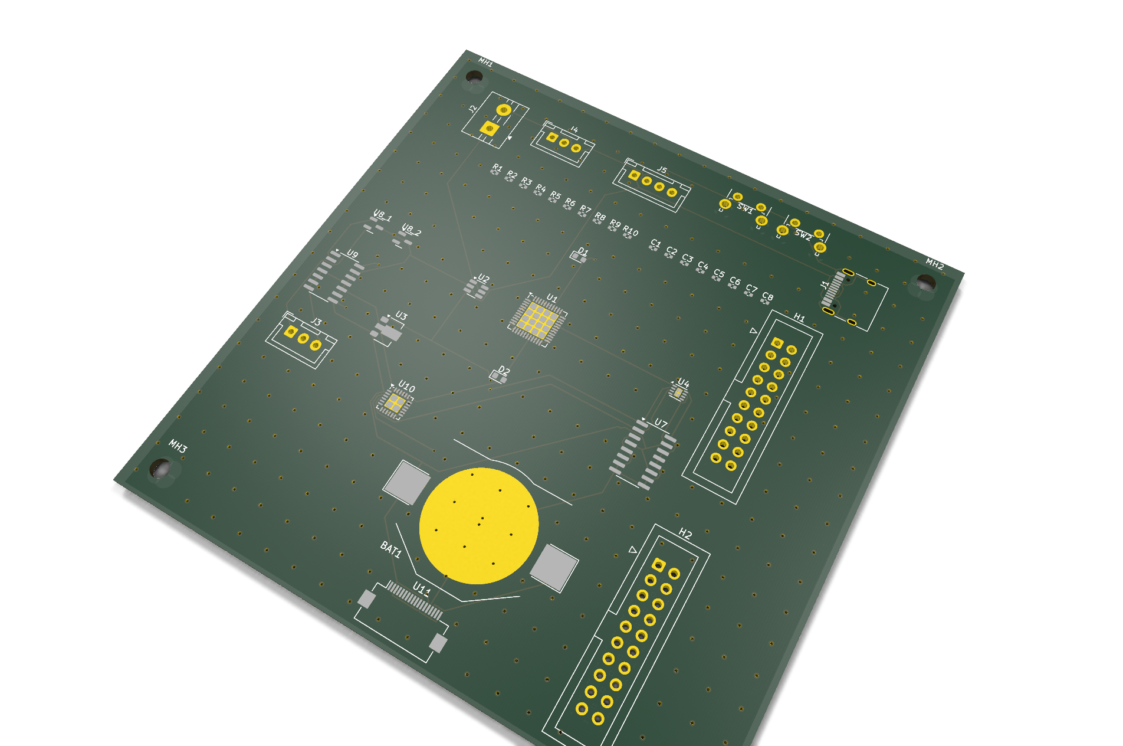
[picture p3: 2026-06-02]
renders/board_iso.png

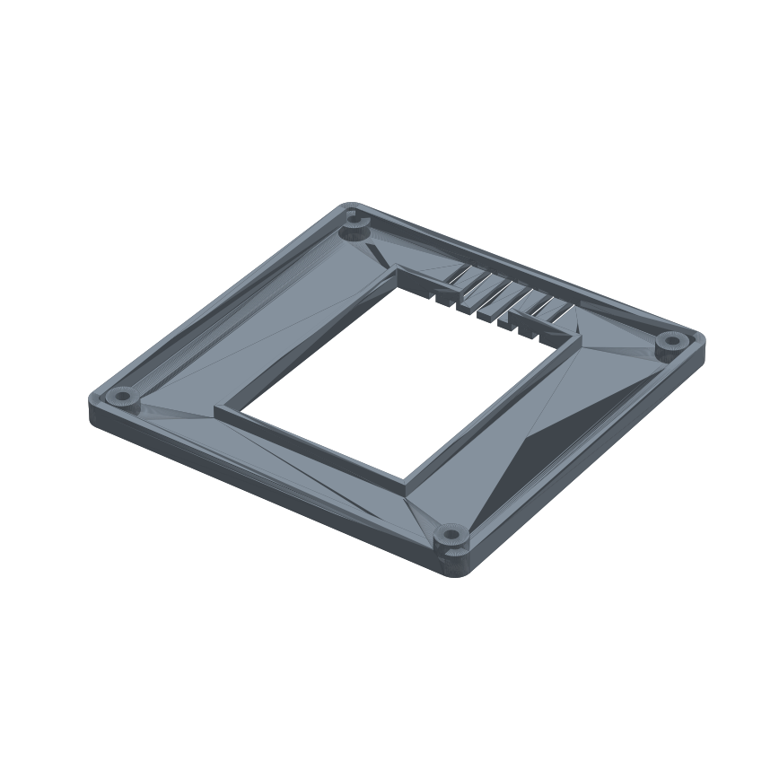
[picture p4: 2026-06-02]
renders/case_lid_inside.png

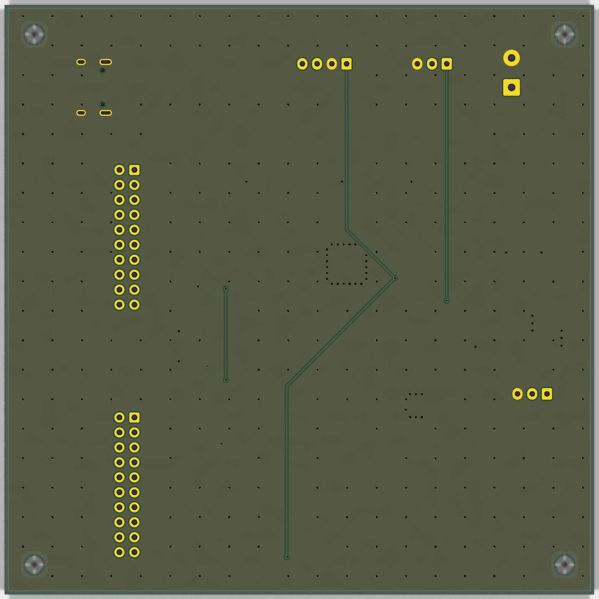
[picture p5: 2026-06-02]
renders/board_bottom.png

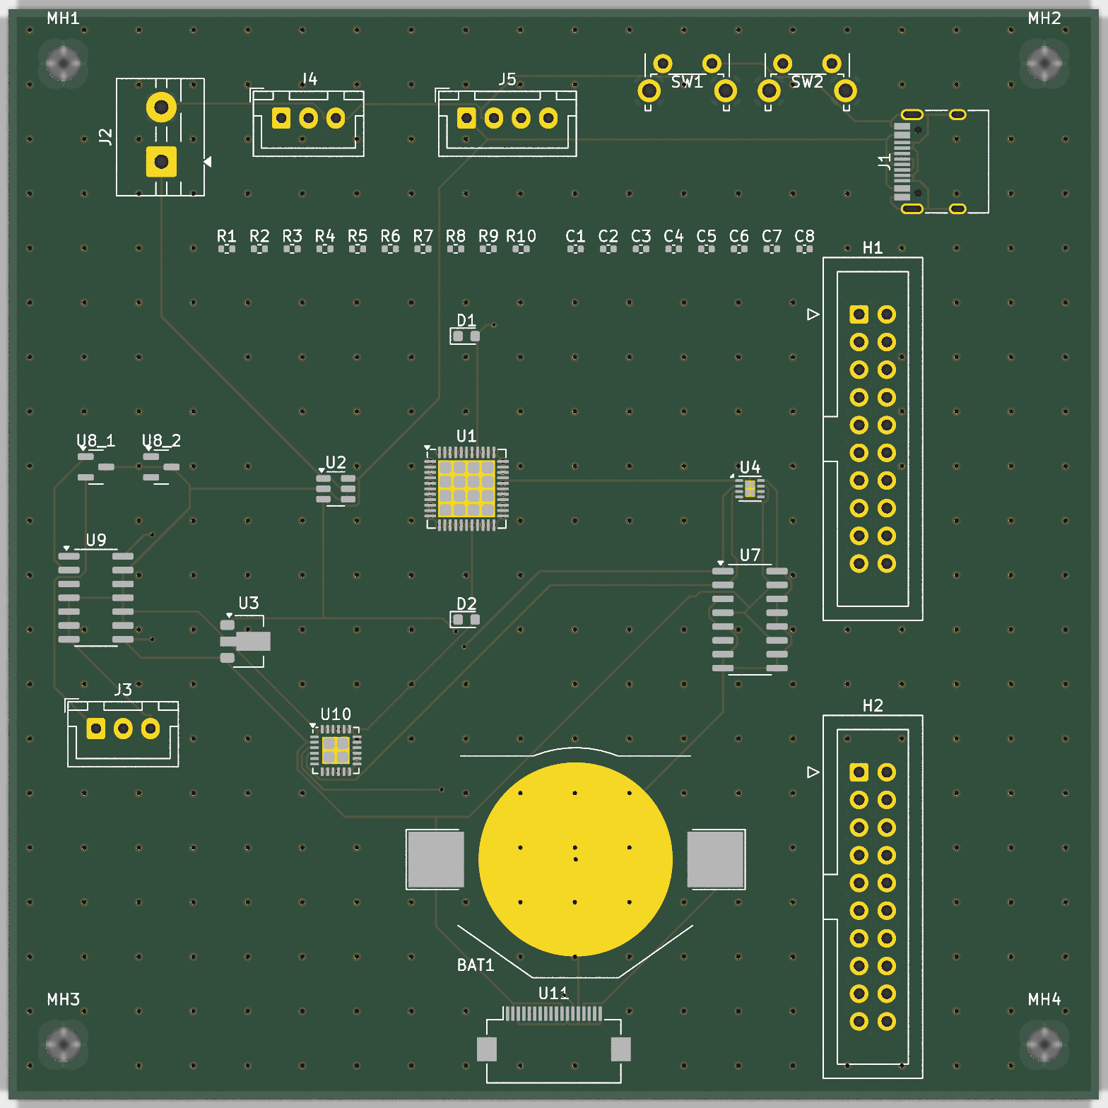
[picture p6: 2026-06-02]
renders/board_top.png

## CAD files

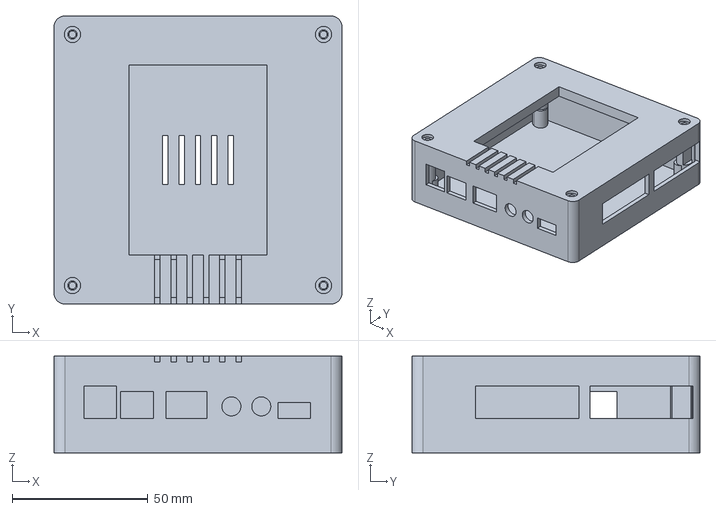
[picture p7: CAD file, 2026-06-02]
kicad/case/DieselFire_case_assembled.step
106.0 x 106.0 x 35.6 mm

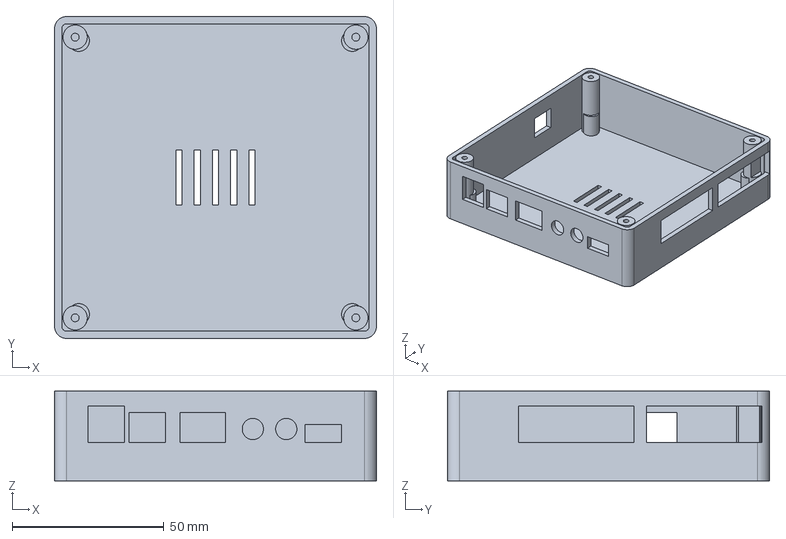
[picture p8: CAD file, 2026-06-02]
kicad/case/DieselFire_case_base.step
106.0 x 106.0 x 29.6 mm

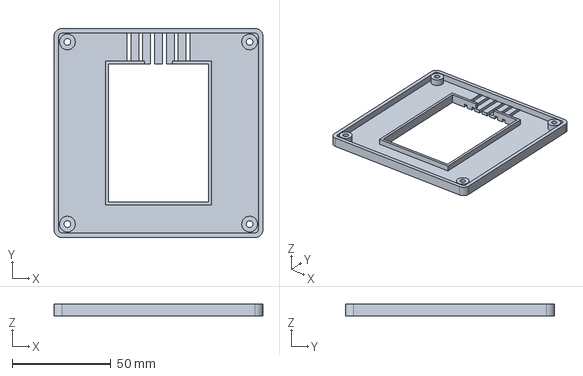
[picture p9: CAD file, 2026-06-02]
kicad/case/DieselFire_case_lid.step
106.0 x 106.0 x 6.00 mm

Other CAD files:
kicad/case/DieselFire_case_base.stl
kicad/case/DieselFire_case_lid.stl

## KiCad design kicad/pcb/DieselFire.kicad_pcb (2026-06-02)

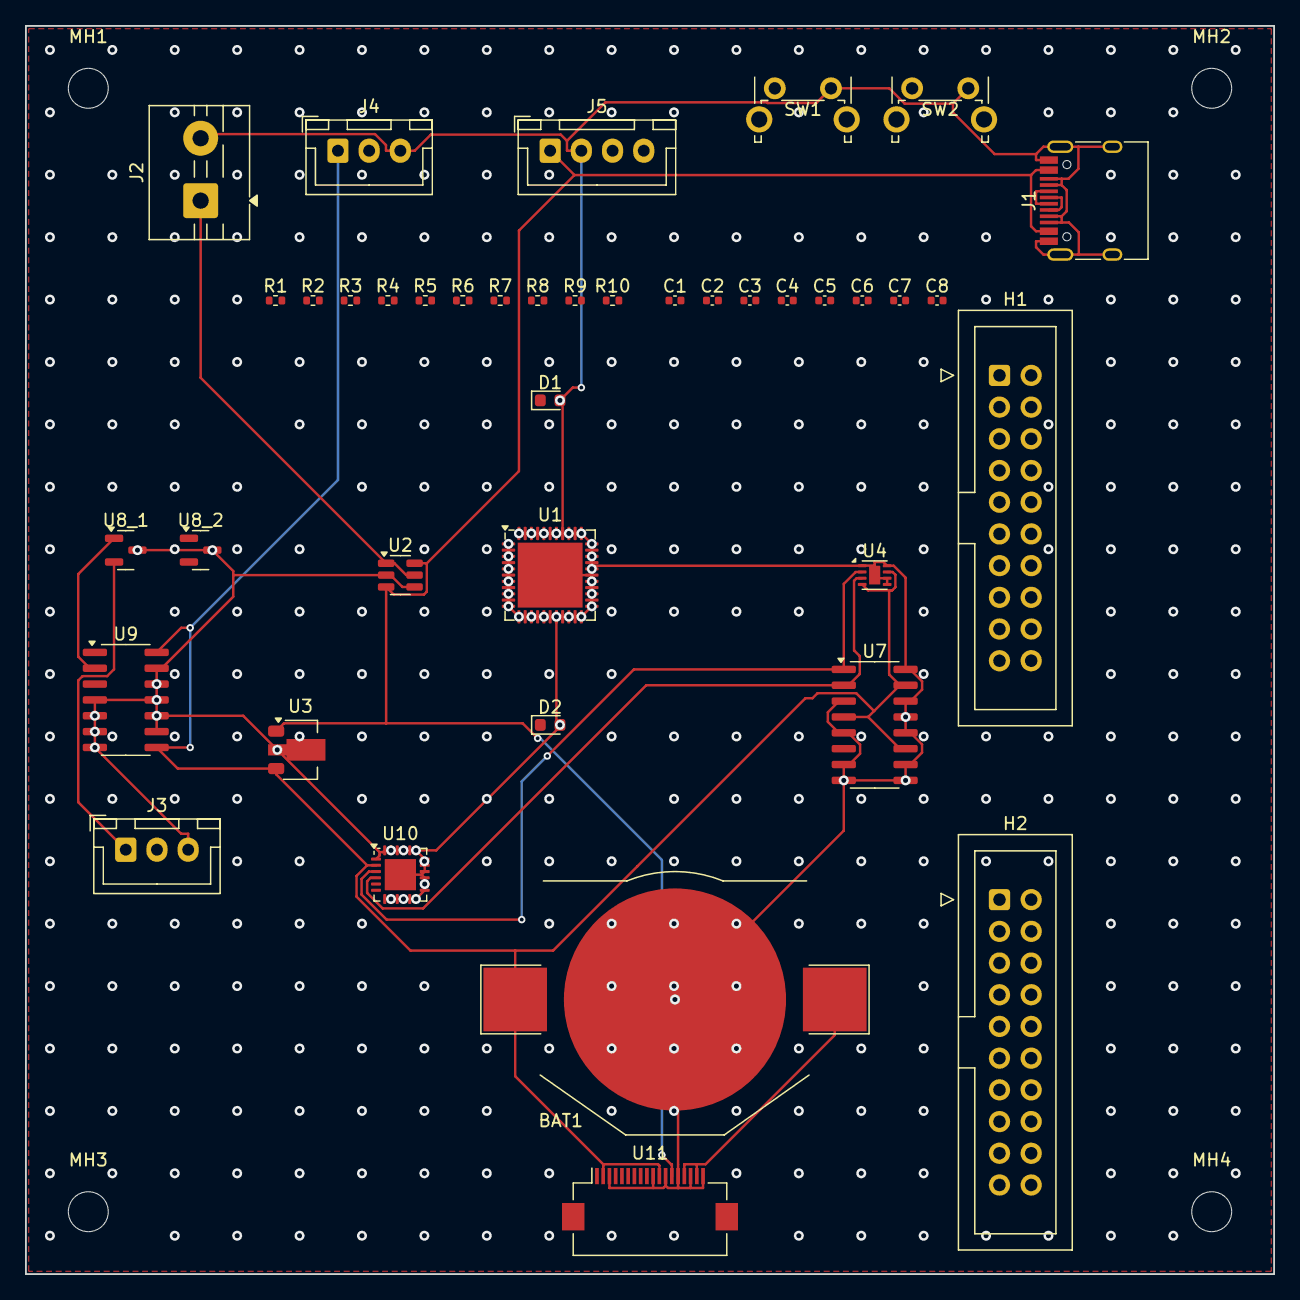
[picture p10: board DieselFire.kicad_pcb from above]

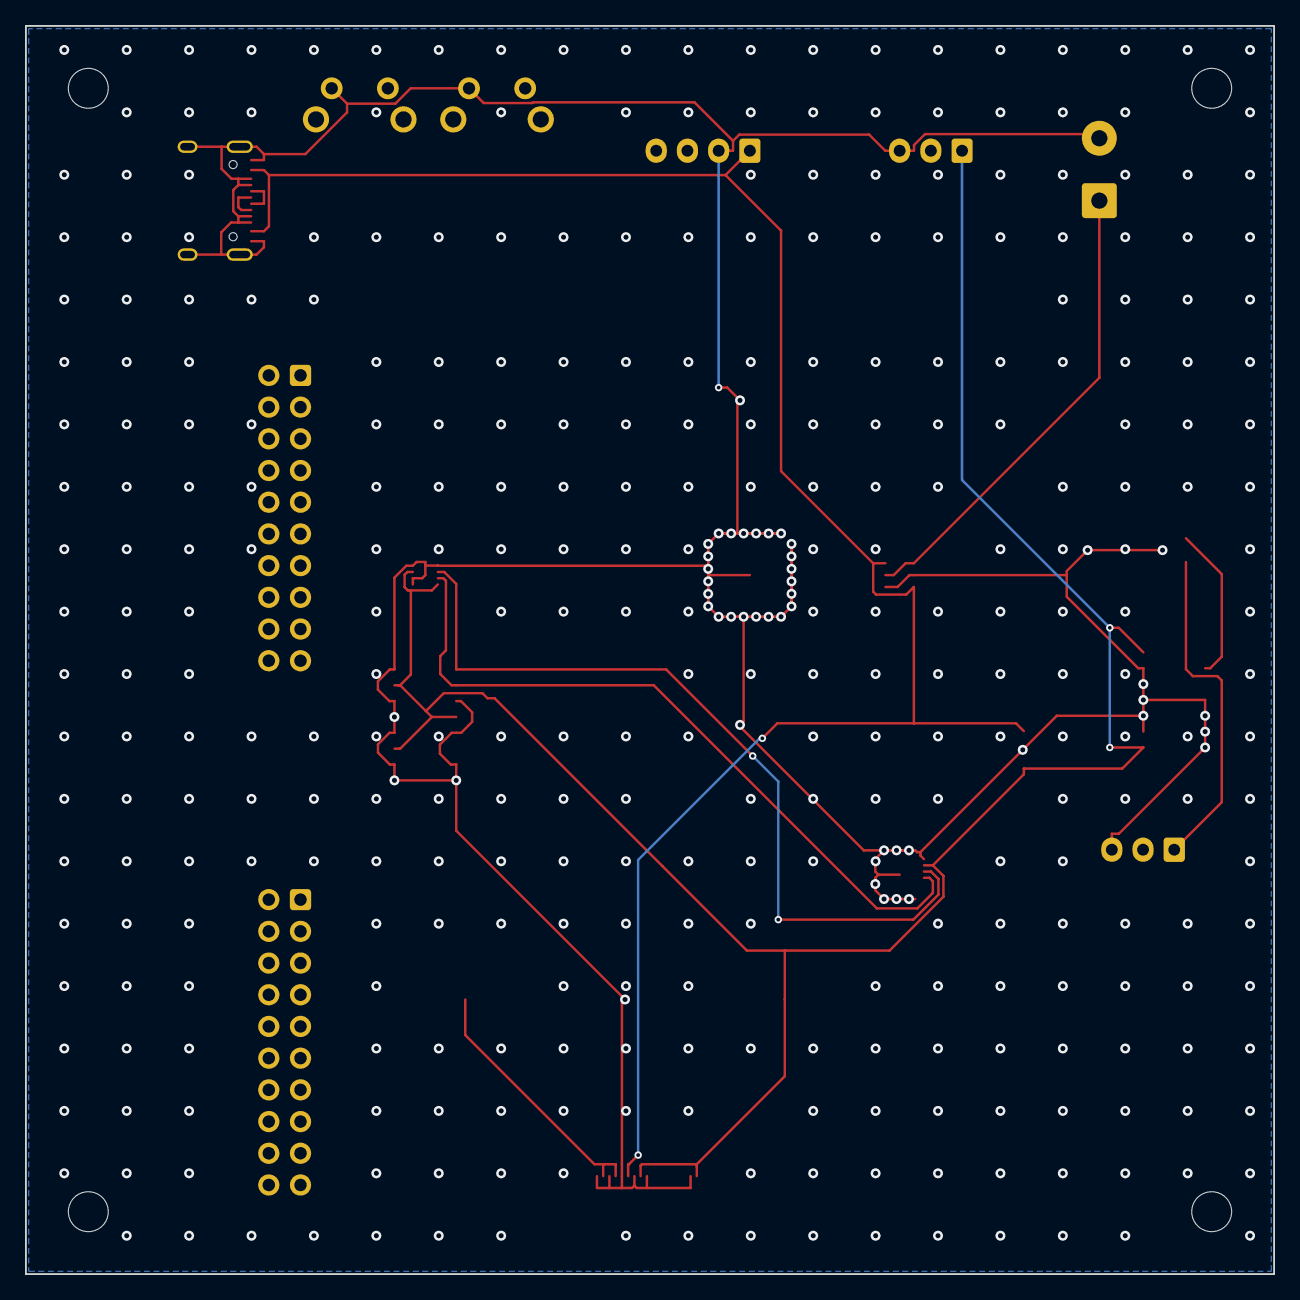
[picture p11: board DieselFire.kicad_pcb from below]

Board: 2 copper layers, 100.0 x 100.0 mm, 44 parts (4 on the bottom side), 10 nets.

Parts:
BAT1: BatteryHolder_Keystone_3002_1x2032
C1, C2, C3, C4, C5, C6, C7, C8: C_0402_1005Metric
D1, D2: LED_0603_1608Metric
H1, H2: IDC-Header_2x10_P2.54mm_Vertical
J1: USB_C_Receptacle_HRO_TYPE-C-31-M-12
J2: TerminalBlock_MaiXu_MX126-5.0-02P_1x02_P5.00mm
J3, J4: JST_XH_B3B-XH-A_1x03_P2.50mm_Vertical
J5: JST_XH_B4B-XH-A_1x04_P2.50mm_Vertical
MH1, MH2, MH3, MH4: MountingHole_3.2mm_M3
R1, R2, R3, R4, R5, R6, R7, R8, R9, R10: R_0402_1005Metric
SW1, SW2: SW_Tactile_SPST_Angled_PTS645Vx39-2LFS
U1: QFN-44-1EP_7x7mm_P0.5mm_EP5.2x5.2mm
U2: SOT-23-6
U3: SOT-89-3
U4: DFN-8-1EP_2x2mm_P0.5mm_EP0.9x1.5mm
U7: SOIC-16_3.9x9.9mm_P1.27mm
U8_1, U8_2: SOT-23
U9: SOIC-14_3.9x8.7mm_P1.27mm
U10: QFN-24-1EP_4x4mm_P0.5mm_EP2.5x2.5mm
U11: Hirose_FH12-18S-0.5SH_1x18-1MP_P0.50mm_Horizontal

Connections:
3V3: BAT1.1, J4.1, U3.3, U4.4, U4.7, U7.4, U7.11, U7.15, U9.8, U9.14, U10.2, U11.2, U11.11, U11.15, U11.17
5V: J1.A4, J1.A9, J1.B4, J1.B9, J5.1, U2.3, U2.6, U3.1, U11.13
12V: J2.1, U2.1, U2.5
BLUE_TX_H: J3.1, U8_1.2
BLUE_TX_OUT: U8_1.1, U9.2
GND: BAT1.2, D1.2, D2.2, J1.A1, J1.A5, J1.A8, J1.A12, J1.B1, J1.B5, J1.B8, J1.B12, J1.S1, J2.2, J3.3, J4.3, J5.2, SW1.2, SW2.2, U1.1, U1.2, U1.3, U1.4, U1.5, U1.6, U1.7, U1.8, U1.9, U1.10, U1.11, U1.12, U1.13, U1.14, U1.15, U1.16, U1.17, U1.18, U1.19, U1.20, U1.21, U1.22, U1.23, U1.24, U1.25, U1.26, U1.27, U1.28, U1.29, U1.30, U1.31, U1.32, U1.33, U1.34, U1.35, U1.36, U1.37, U1.38, U1.39, U1.40, U1.41, U1.42, U1.43, U1.44, U1.45, U2.2, U2.4, U3.2, U4.1, U4.5, U4.6, U4.8, U4.9, U7.3, U7.5, U7.7, U7.8, U7.9, U7.10, U7.12, U7.13, U7.14, U7.16, U8_1.3, U8_2.3, U9.4, U9.5, U9.6, U9.7, U9.9, U9.10, U9.11, U9.12, U9.13, U10.1, U10.7, U10.8, U10.9, U10.10, U10.11, U10.12, U10.13, U10.14, U10.15, U10.16, U10.17, U10.18, U10.19, U10.20, U10.21, U10.22, U10.23, U10.24, U10.25, U11.3, U11.10, U11.12, U11.14, U11.16, U11.18
I2C_SCL: U4.3, U7.2, U10.4
I2C_SDA: U4.2, U7.1, U10.3
USB_D+: J1.A6, J1.B6
USB_D-: J1.A7, J1.B7

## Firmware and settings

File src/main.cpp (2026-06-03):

/*
 * This file is part of the "DieselFire" distribution 
 * (https://dieselfire.wabo.cc) 
 *
 * Copyright (C) 2019  Ray Jones <ray@mrjones.id.au>
 * Copyright (C) 2018  James Clark
 *
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
 */

  /*
  Chinese Heater Half Duplex Serial Data Sending Tool

  Connects to the blue wire of a Chinese heater, which is the half duplex serial link.
  Sends and receives data from hardware serial port 1. 

  Terminology: Tx is to the heater unit, Rx is from the heater unit.
  
  Typical data frame timing on the blue wire is:
  __Tx_Rx____________________________Tx_Rx____________________________Tx_Rx___________
  
  This software can connect to the blue wire in a normal OEM system, detecting the 
  OEM controller and allowing extraction of the data or injecting on/off commands.

  If Pin 21 is grounded on the Due, this simple stream will be reported over Serial and
  no control from the Arduino will be allowed.
  This allows passive sniffing of the blue wire in a normal system.
  
  The binary data is received from the line.
  If it has been > 100ms since the last blue wire activity this indicates a new frame 
  sequence is starting from the OEM controller.
  Synchronise as such then count off the next 24 bytes storing them in the Controller's 
  data array. These bytes are then reported over Serial to the PC in ASCII.

  It is then expected the heater will respond with it's 24 bytes.
  Capture those bytes and store them in the Heater1 data array.
  Once again these bytes are then reported over Serial to the PC in ASCII.

  If no activity is sensed in a second, it is assumed no OEM controller is attached and we
  have full control over the heater.

  Either way we can now inject a message onto the blue wire allowing our custom 
  on/off control.
  We must remain synchronous with an OEM controller if it exists otherwise E-07 
  faults will be caused.

  Typical data frame timing on the blue wire is then:
  __OEMTx_HtrRx__OurTx_HtrRx____________OEMTx_HtrRx__OurTx_HtrRx____________OEMTx_HtrRx__OurTx_HtrRx_________
    
  The second HtrRx to the next OEMTx delay is always > 100ms and is paced by the OEM controller.
  The delay before seeing Heater Rx data after any Tx is usually much less than 10ms.
  But this does rise if new max/min or voltage settings are sent.
  **The heater only ever sends Rx data in response to a data frame from a controller**

  For Bluetooth connectivity, a HC-05 Bluetooth module is attached to Serial2:
  TXD -> Rx2 (pin 17)
  RXD -> Tx2 (pin 16)
  EN(key) -> pin 15
  STATE -> pin 4
  
 
  This code only works with boards that have more than one hardware serial port like Arduino 
  Mega, Due, Zero, ESP32 etc.


  The circuit:
  - a Tx Rx multiplexer is required to combine the Arduino's Tx1 And Rx1 pins onto the blue wire.
  - a Tx Enable signal from pin 22 controls the multiplexer, high for Tx, low for Rx
  - Serial logging software on Serial0 via USB link

  created 23 Sep 2018 by Ray Jones

  This example code is in the public domain.
*/

#include "WiFi/DFMQTT.h"
#include "cfg/DFConfig.h"
#include "cfg/pins.h"
#include "RTC/Timers.h"
#include "RTC/Clock.h"
#include "RTC/RTCStore.h"
#include "WiFi/DFWifi.h"
#include "WiFi/DFWebServer.h"
#include "WiFi/DFota.h"
#include "Protocol/Protocol.h"
#include "Protocol/TxManage.h"
#include "Protocol/SmartError.h"
#include "Utility/helpers.h" 
#include "Utility/NVStorage.h"
#include "Utility/DebugPort.h"
#include "Utility/macros.h"
#include "Utility/UtilClasses.h"
#include "Utility/DF_JSON.h"
#include "Utility/DF_GPIO.h"
#include "Utility/BoardDetect.h"
#include "Utility/FuelGauge.h"
#if !USE_ILI9341_DISPLAY
#include "OLED/ScreenManager.h"
#include "OLED/KeyPad.h"
#endif
#include "Utility/TempSense.h"
#include "Utility/DataFilter.h"
#include "Utility/HourMeter.h"
#include <rom/rtc.h>
#include <esp_spiffs.h>
#include <SPIFFS.h>
#include <nvs.h>
#include "Utility/MQTTsetup.h"
#include <FreeRTOS.h>
#include "RTC/TimerManager.h"
#include "Utility/GetLine.h"
#include "Utility/DemandManager.h"
#include "Protocol/BlueWireTask.h"
#include "Protocol/433MHz.h"
#include "Utility/MQCOSensor.h"

#if USE_ILI9341_DISPLAY
#include "Display/LVGLDisplay.h"
#endif

#if USE_TWDT == 1
#include "esp_task_wdt.h"
#endif

// SSID & password now stored in NV storage - these are still the default values.
//#define AP_SSID "DieselFire"
//#define AP_PASSWORD "thereisnospoon"

// #define RX_DATA_TIMOUT 50

const int FirmwareRevision = 1;
const int FirmwareSubRevision = 0;
const int FirmwareMinorRevision = 0;  // non-zero indicates beta version
const char* FirmwareDate = __DATE__;

/*
 * Macro to check the outputs of TWDT functions and trigger an abort if an
 * incorrect code is returned.
 */
#define TWDT_TIMEOUT_S 15
#define CHECK_ERROR_CODE(returned, expected) ({                        \
            if(returned != expected){                                  \
                printf("TWDT ERROR\n");                                \
                abort();                                               \
            }                                                          \
})


#ifdef ESP32
#include "Bluetooth/BluetoothESP32.h"
#else
#include "Bluetooth/BluetoothHC05.h"
#endif

bool validateFrame(const CProtocol& frame, const char* name);
#if !USE_ILI9341_DISPLAY
void checkDisplayUpdate();
#endif
void checkDebugCommands();
void manageStopStartMode();
void manageCyclicMode();
void manageFrostMode();
void manageHumidity();
void doStreaming();
void heaterOn();
void heaterOff();
void updateFilteredData(CProtocol& HeaterInfo);
bool HandleMQTTsetup(char rxVal);
void showMainmenu();
bool checkTemperatureSensors();
void checkBlueWireEvents();
void checkUHF();

// DS18B20 temperature sensor support
// Uses the RMT timeslot driver to operate as a one-wire bus
//CBME280Sensor BMESensor;
CTempSense TempSensor;
CMQCOSensor MQ7;
long lastTemperatureTime;            // used to moderate DS18B20 access
int DS18B20holdoff = 2;

int BoardRevision = 0;
bool bTestBTModule = false;
bool bSetupMQTT = false;
bool bReportStack = false;

unsigned long lastAnimationTime;     // used to sequence updates to LCD for animation

sFilteredData FilteredSamples;
CSmartError SmartError;
#if USE_ILI9341_DISPLAY
LVGLDisplay display;
#else
CKeyPad KeyPad;
CScreenManager ScreenManager;
#endif
DFTelnetSpy DebugPort;

#if USE_JTAG == 0
//CANNOT USE GPIO WITH JTAG DEBUG
CGPIOin GPIOin;
CGPIOout GPIOout;
CGPIOalg GPIOalg;
#endif

CMQTTsetup MQTTmenu;
CSecuritySetup SecurityMenu;

TaskHandle_t handleWatchdogTask;
TaskHandle_t handleBlueWireTask;
extern TaskHandle_t handleWebServerTask;

// these variables will persist over a soft reboot.
__NOINIT_ATTR float persistentRunTime;
__NOINIT_ATTR float persistentGlowTime;

CFuelGauge FuelGauge; 
CRTC_Store RTC_Store;
CHourMeter* pHourMeter = NULL;

bool bReportBlueWireData = REPORT_RAW_DATA;
bool bReportJSONData = REPORT_JSON_TRANSMIT;
bool bReportRecyleEvents = REPORT_BLUEWIRE_RECYCLES;
bool bReportOEMresync = REPORT_OEM_RESYNC;
bool pair433MHz = false;

CProtocol BlueWireRxData;
CProtocol BlueWireTxData;
CProtocolPackage BlueWireData;

bool bUpdateDisplay = false;
bool bHaveWebClient = false;
bool bBTconnected = false;
long BootTime;

////////////////////////////////////////////////////////////////////////////////////////////////////////
//               Bluetooth instantiation
//
#ifdef ESP32

// Bluetooth options for ESP32
#if USE_HC05_BLUETOOTH == 1
CBluetoothESP32HC05 Bluetooth(HC05_KeyPin, HC05_SensePin, Rx2Pin, Tx2Pin); // Instantiate ESP32 using a HC-05
#elif USE_BLE_BLUETOOTH == 1
CBluetoothESP32BLE Bluetooth;              // Instantiate ESP32 BLE server
#elif USE_CLASSIC_BLUETOOTH == 1
CBluetoothESP32Classic Bluetooth;          // Instantiate ESP32 Classic Bluetooth server
#else   // none selected
CBluetoothAbstract Bluetooth;           // default no bluetooth support - empty shell
#endif  

#else   //  !ESP32

// Bluetooth for boards other than ESP32
#if USE_HC05_BLUETOOTH == 1
CBluetoothHC05 Bluetooth(HC05_KeyPin, HC05_SensePin);  // Instantiate a HC-05
#else   // none selected  
CBluetoothAbstract Bluetooth;           // default no bluetooth support - empty shell
#endif  // closing USE_HC05_BLUETOOTH

#endif  // closing ESP32
//
//                 END Bluetooth instantiation
////////////////////////////////////////////////////////////////////////////////////////////////////////



////////////////////////////////////////////////////////////////////////////////////////////////////////
// setup Non Volatile storage
// this is very much hardware dependent, we can use the ESP32's FLASH
//
#ifdef ESP32
CESP32HeaterStorage actualNVstore;
#else
CHeaterStorage actualNVstore;   // dummy, for now
#endif

  // create reference to CHeaterStorage
  // via the magic of polymorphism we can use this to access whatever 
  // storage is required for a specific platform in a uniform way
CHeaterStorage& NVstore = actualNVstore;

//
////////////////////////////////////////////////////////////////////////////////////////////////////////

CBluetoothAbstract& getBluetoothClient() 
{
  return Bluetooth;
}

char taskMsg[BLUEWIRE_MSGQUEUESIZE];

void checkBlueWireEvents()
{
// collect and report any debug messages from the blue wire task
  if(BlueWireMsgQueue && xQueueReceive(BlueWireMsgQueue, taskMsg, 0))
    DebugPort.print(taskMsg);

  // check for complted data exchange from the blue wire task
  if(BlueWireSemaphore && xSemaphoreTake(BlueWireSemaphore, 0)) {
    updateJSONclients(bReportJSONData);
    updateMQTT();
    NVstore.doSave();   // now is a good time to store to the NV storage, well away from any blue wire activity
  }

  // collect transmitted heater data from blue wire task
  if(BlueWireTxQueue && xQueueReceive(BlueWireTxQueue, BlueWireTxData.Data, 0)) {
  }

  // collect and process received heater data from blue wire task
  if(BlueWireRxQueue && xQueueReceive(BlueWireRxQueue, BlueWireRxData.Data, 0)) {
    BlueWireData.set(BlueWireRxData, BlueWireTxData);
    SmartError.monitor(BlueWireRxData);

    updateFilteredData(BlueWireRxData);

    FuelGauge.Integrate(BlueWireRxData.getPump_Actual());

    if(INBOUNDS(BlueWireRxData.getRunState(), 1, 5)) {  // check for Low Voltage Cutout
      SmartError.checkVolts(FilteredSamples.FastipVolts.getValue(), FilteredSamples.FastGlowAmps.getValue());
      SmartError.checkfuelUsage();
    }

    // trap being in state 0 with a heater error - cancel user on memory to avoid unexpected cyclic restarts
    if(RTC_Store.getUserStart() && (BlueWireRxData.getRunState() == 0) && (BlueWireRxData.getErrState() > 1)) {
      DebugPort.println("Forcing cyclic cancel due to error induced shutdown");
      // DebugPort.println("Forcing cyclic cancel due to error induced shutdown");
      RTC_Store.setUserStart(false);
    }

    pHourMeter->monitor(BlueWireRxData);
  }
}


// callback function for Keypad events.
// must be an absolute function, cannot be a class member due the "this" element!
#if !USE_ILI9341_DISPLAY
void parentKeyHandler(uint8_t event) 
{
  ScreenManager.keyHandler(event);   // call into the Screen Manager
}
#endif

void interruptReboot()
{     
  ets_printf("%ld Software watchdog reboot......\r\n", millis());
  abort();
  // esp_restart();
}

unsigned long WatchdogTick = -1;
unsigned long JSONWatchdogTick = -1;

void WatchdogTask(void * param)
{
  for(;;) {
    if(WatchdogTick >= 0) {
      if(WatchdogTick == 0) {
        interruptReboot();
      }
      else {
        WatchdogTick--;
      }
    }
    if(JSONWatchdogTick >= 0) {
      if(JSONWatchdogTick == 0) {
        interruptReboot();
      }
      else {
        JSONWatchdogTick--;
      }
    }
    vTaskDelay(10);
  }
}



//**************************************************************************************************
//**                                                                                              **
//**         WORKAROUND for crap ESP32 millis() standard function                                 **
//**                                                                                              **
//**************************************************************************************************
//
// Substitute shitfull ESP32 millis() with a true and proper ms counter
// The standard millis() on ESP32 is actually micros()/1000.
// This wraps every 71.5 minutes in a **very non linear fashion**.
//
// The FreeRTOS Tick Counter however does increment each ms, and rolls naturally past 0 every 49days.
// With this proper linear behaviour you can use valid timeout calcualtions even through wrap around.
// This elegance breaks using the standard library function, leading to many weird and obtuse issues.
//
// *** IMPORTANT ***
//
// You **MUST** use --wrap millis in the linker command, or -Wl,--wrap,millis in the GCC command.
// platformio.ini file for this project defines the latter as a build_flags entry.
//
// The linker will now link to __wrap_millis() instead of millis() for *any* usage of millis().
// Best of all this includes any library usages of millis() :-D
// If you really must call the shitty ESP32 Arduino millis(), you must call __real_millis() 
// from your dubious code ;-) - basically DON'T do this.
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
void loop() 
{
  // DebugPort.handle();    // keep telnet spy alive

  feedWatchdog(); // feed watchdog
      
  doStreaming();   // do wifi, BT tx etc 

  Clock.update();

  if(checkTemperatureSensors()) {
#if !USE_ILI9341_DISPLAY
    ScreenManager.reqUpdate();
#endif
  }

#if !USE_ILI9341_DISPLAY
  checkDisplayUpdate();
#else
  display.taskHandler();
  static unsigned long lastBlink = 0;
  if (millis() - lastBlink > 500) {
    lastBlink = millis();
    digitalWrite(LED_STATUS, !digitalRead(LED_STATUS));
  }
#endif

  checkBlueWireEvents();

  checkUHF();

  vTaskDelay(1);
}  // loop


bool checkTemperatureSensors()
{
  long tDelta = millis() - lastTemperatureTime;
  if(tDelta > MIN_TEMPERATURE_INTERVAL) {  // maintain a minimum holdoff period
    lastTemperatureTime = millis();    // reset time to observe temeprature        

    if(bReportStack) {
      DebugPort.println("Stack high water marks");
      DebugPort.printf("  Arduino: %d\r\n", uxTaskGetStackHighWaterMark(NULL));
      DebugPort.printf("  BlueWire: %d\r\n", uxTaskGetStackHighWaterMark(handleBlueWireTask));
      DebugPort.printf("  Watchdog: %d\r\n", uxTaskGetStackHighWaterMark(handleWatchdogTask));
      DebugPort.printf("  SSL loop: %d\r\n", uxTaskGetStackHighWaterMark(handleWebServerTask));
    }

    TempSensor.readSensors();

    float fTemperature;
    if(TempSensor.getTemperature(0, fTemperature)) {  // get Primary sensor temperature
      if(DS18B20holdoff) {
        DS18B20holdoff--; 
        DebugPort.printf("Skipped initial DS18B20 reading: %f\r\n", fTemperature);
      }                           // first value upon sensor connect is bad
      else {
        // exponential mean to stabilse readings
        FilteredSamples.AmbientTemp.update(fTemperature);

        manageCyclicMode();
        manageFrostMode();
#if USE_MQ7 == 1
        MQ7.read();
#endif
        manageHumidity();
        manageStopStartMode();
      }
    }
    else {
      DS18B20holdoff = 3;
      FilteredSamples.AmbientTemp.reset(-100.0);
    }

    TempSensor.startConvert();  // request a new conversion, will be ready by the time we loop back around

    return true;
  }
  return false;
}

void manageStopStartMode()
{
  if(NVstore.getUserSettings().ThermostatMethod == 4 && RTC_Store.getUserStart() ) {
    float deltaT = getTemperatureSensor() - CDemandManager::getDegC(); 
    float thresh = NVstore.getUserSettings().ThermostatWindow/2;
    int heaterState = getHeaterInfo().getRunState();   // native heater state
    if(deltaT > thresh) {
      if(heaterState > 0 && heaterState <= 5) {  
        DebugPort.printf("STOP START MODE: Stopping heater, deltaT > +%.1f\r\n", thresh);
        heaterOff();    // over temp - request heater stop
      }
    }
    if(deltaT < -thresh) {
      if(heaterState == 0) {
        DebugPort.printf("STOP START MODE: Restarting heater, deltaT <%.1f\r\n", thresh);
        heaterOn();  // under temp, start heater again
      }
    }
  }
}

void manageCyclicMode()
{
  const sCyclicThermostat& cyclic = NVstore.getUserSettings().cyclic;
  if(cyclic.Stop && RTC_Store.getUserStart()) {   // cyclic mode enabled, and user has started heater
    int stopDeltaT = cyclic.Stop + 1;  // bump up by 1 degree - no point invoking at 1 deg over!
    float deltaT = getTemperatureSensor() - CDemandManager::getDegC(); 
//    DebugPort.printf("Cyclic=%d bUserOn=%d deltaT=%d\r\n", cyclic, bUserON, deltaT);

    // ensure we cancel user ON mode if heater throws an error
    int errState = getHeaterInfo().getErrState();
    if((errState > 1) && (errState < 12) && (errState != 8)) {
      // excludes errors 0,1(OK), 12(E1-11,Retry) & 8(E-07,Comms Error)
      DebugPort.println("CYCLIC MODE: cancelling user ON status"); 
      requestOff();   // forcibly cancel cyclic operation - pretend user pressed OFF
    }
    int heaterState = getHeaterInfo().getRunState();
    // check if over temp, turn off heater
    if(deltaT > stopDeltaT) {
      if(heaterState > 0 && heaterState <= 5) {  
        DebugPort.printf("CYCLIC MODE: Stopping heater, deltaT > +%d\r\n", stopDeltaT);
        heaterOff();    // over temp - request heater stop
      }
    }
    // check if under temp, turn on heater
    if(deltaT < cyclic.Start) {
      // typ. 1 degree below set point - restart heater
      if(heaterState == 0) {
        DebugPort.printf("CYCLIC MODE: Restarting heater, deltaT <%d\r\n", cyclic.Start);
        heaterOn();
      }
    }
  }
}


void manageFrostMode()
{
  uint8_t engage = NVstore.getUserSettings().FrostOn;
  if(engage) {
    float deltaT = getTemperatureSensor() - engage;
    int heaterState = getHeaterInfo().getRunState();
    if(deltaT < 0) {
      if(heaterState == 0) {
        RTC_Store.setFrostOn(true);        
        DebugPort.printf("FROST MODE: Starting heater, < %d`C\r\n", engage);
        if(NVstore.getUserSettings().FrostRise == 0)
          RTC_Store.setUserStart(true);    // enable cyclic mode if user stop
        heaterOn();
      }
    }
    uint8_t rise = NVstore.getUserSettings().FrostRise;
    if(rise && (deltaT > rise)) {  // if rise is set to 0, user must shut off heater
      if(RTC_Store.getFrostOn()) {
        DebugPort.printf("FROST MODE: Stopping heater, > %d`C\r\n", engage+rise);
        heaterOff();
        RTC_Store.setFrostOn(false);  // cancel active frost mode
        RTC_Store.setUserStart(false);   // for cyclic mode
      }
    }
  }
}

void manageHumidity()
{
  uint8_t humidity = NVstore.getUserSettings().humidityStart;
  if(humidity) {
    float reading;
    if(getTempSensor().getHumidity(reading)) {
      uint8_t testval = (uint8_t)reading;
      if(testval > humidity) {
        DebugPort.printf("HUMIDITY MODE: Starting heater, > %d%%\r\n", humidity);
        requestOn();
      }
    }
  }
}


CDemandManager::eStartCode 
requestOn()
{
  DebugPort.println("Start Request!");
  bool fuelOK = 2 != SmartError.checkfuelUsage();
  if(!fuelOK) {
    DebugPort.println("Start denied - Low fuel");
    return CDemandManager::eStartLowFuel;
  }
  bool LVCOK = 2 != SmartError.checkVolts(FilteredSamples.FastipVolts.getValue(), FilteredSamples.FastGlowAmps.getValue());
  if(hasHtrData() && LVCOK) {
    RTC_Store.setUserStart(true);    // for cyclic mode
    RTC_Store.setFrostOn(false);         // cancel frost mode
    // only start if below appropriate temperature threshold, raised for cyclic mode
    // int denied = checkStartTemp();
    CDemandManager::eStartCode startCode = CDemandManager::checkStart();
    if(startCode == CDemandManager::eStartOK) {
      heaterOn();
    }
    else {
      if(startCode == CDemandManager::eStartSuspend) {
        SmartError.inhibit(true);  // ensure our suspend does not get immediately cancelled by prior error sitting in system!
        DebugPort.printf("CYCLIC MODE: Skipping directly to suspend, deltaT > +%d\r\n", NVstore.getUserSettings().cyclic.Stop+1);
        heaterOff();    // over temp - request heater stop
      }
    }
    return startCode;
  }
  else {
    DebugPort.println("Start denied - LVC");
    return CDemandManager::eStartLVC;   // LVC
  }
}

void requestOff()
{
  DebugPort.println("Stop Request!");
  heaterOff();
  RTC_Store.setUserStart(false);   // for cyclic mode
  RTC_Store.setFrostOn(false);  // cancel active frost mode
  CTimerManager::cancelActiveTimer();
}

void heaterOn() 
{
  TxManage.queueOnRequest();
  SmartError.reset();
}

void heaterOff()
{
  TxManage.queueOffRequest();
  SmartError.inhibit();
}


#if !USE_ILI9341_DISPLAY
void checkDisplayUpdate()
{
  // only update OLED when not processing blue wire
  if(ScreenManager.checkUpdate()) {
    lastAnimationTime = millis() + 100; 
    ScreenManager.animate();
    ScreenManager.refresh();   // always refresh post major update
  }
 
  long tDelta = millis() - lastAnimationTime;
  if(tDelta >= 100) {
    lastAnimationTime = millis() + 100; 
    if(ScreenManager.animate())
      ScreenManager.refresh();
  }
}
#endif

void forceBootInit()
{
  RTC_Store.setBootInit();
}


float getTemperatureSensor(int source)
{
  float retval;
  TempSensor.getTemperature(source, retval);
  return retval;

}


bool isWebClientConnected()
{
  return bHaveWebClient;
}

void checkDebugCommands()
{
  static CGetLine line;

  // check for test commands received over Debug serial port or telnet
  char rxVal;
  if(DebugPort.getch(rxVal)) {

#ifdef PROTOCOL_INVESTIGATION    
    static int mode = 0;6
    static int val = 0;
#endif

    if(bTestBTModule) {
      bTestBTModule = Bluetooth.test(rxVal);
      return;
    }
    if(MQTTmenu.Handle(rxVal)) {
      if(rxVal == 0) {
        showMainmenu();
      }
      return;
    }
    if(SecurityMenu.Handle(rxVal)) {
      if(rxVal == 0) {
        showMainmenu();
      }
      return;
    }

    rxVal = toLowerCase(rxVal);
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

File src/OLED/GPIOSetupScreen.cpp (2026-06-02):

/*
 * This file is part of the "DieselFire" distribution 
 * (https://dieselfire.wabo.cc) 
 *
 * Copyright (C) 2018  Ray Jones <ray@mrjones.id.au>
 *
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
 */

#include "128x64OLED.h"
#include "GPIOSetupScreen.h"
#include "KeyPad.h"
#include "../Utility/NVStorage.h"
#include "../Utility/DF_GPIO.h"
#include "fonts/Icons.h"
#include "../Utility/BoardDetect.h"

extern CGPIOout GPIOout;
extern CGPIOin GPIOin;
extern CGPIOalg GPIOalg;

int8_t s8abs(int8_t val) 
{
  if(val >= 0)
    return val;
  else
    return -val;
}

///////////////////////////////////////////////////////////////////////////
//
// CGPIOSetupScreen
//
// This screen provides control over GPIO features
//
///////////////////////////////////////////////////////////////////////////

static const int Line3 = 14;
static const int Line2 = 27;
static const int Line1 = 40;
static const int Column1 = 19;
static const int Column2 = 88;

CGPIOSetupScreen::CGPIOSetupScreen(C128x64_OLED& display, CScreenManager& mgr) : CUIEditScreen(display, mgr) 
{
  _initUI();
  _GPIOparams.in1Mode = CGPIOin1::Disabled;
  _GPIOparams.in2Mode = CGPIOin2::Disabled;
  _GPIOparams.out1Mode = CGPIOout1::Disabled;
  _GPIOparams.out2Mode = CGPIOout2::Disabled;
  _GPIOparams.algMode = CGPIOalg::Disabled;
  _GPIOparams.thresh[0] = 0;
  _GPIOparams.thresh[1] = 0;
  _ExtHold = 0;
}

void 
CGPIOSetupScreen::onSelect()
{
  CUIEditScreen::onSelect();
  _GPIOparams = NVstore.getUserSettings().GPIO;
  _ExtHold = NVstore.getUserSettings().ExtThermoTimeout;
  _repeatCount = -1;
}


bool 
CGPIOSetupScreen::show()
{
  char msg[16];

  _display.clearDisplay();

  static bool animated = false;
  animated = !animated;

  if(!CUIEditScreen::show()) {  // for showing "saving settings"

    _showTitle("GPIO Configuration");
    _drawBitmap(0, Line3, InputIconInfo);
    _drawBitmap(11, Line3, _1IconInfo);
    {
      const char* msgText = NULL;
      switch(_GPIOparams.in1Mode) {
        case CGPIOin1::Disabled:  msgText = " ---  "; break;
        case CGPIOin1::Start:     msgText = "Start "; break;
        case CGPIOin1::Run:       msgText = "Run   "; break;
        case CGPIOin1::StartStop: msgText = animated ? "Start " : "Stop  "; break;
        case CGPIOin1::Stop:      msgText = "Stop  "; break;
      }
      if(msgText)
        _printMenuText(Column1, Line3, msgText, _rowSel == 4);
    }
    _drawBitmap(0, Line2, InputIconInfo);
    _drawBitmap(11, Line2, _2IconInfo);
    {
      const char* msgText = NULL;
      switch(_GPIOparams.in2Mode) {
        case CGPIOin2::Disabled:    msgText = " ---  "; break;
        case CGPIOin2::Stop:        msgText = "Stop  "; break;
        case CGPIOin2::Thermostat:  msgText = "\352T "; break;
        case CGPIOin2::FuelReset:   msgText = "Fuel 0"; break;
      }
      if(msgText)
        _printMenuText(Column1, Line2, msgText, _rowSel == 2);
      
      if(_GPIOparams.in2Mode == CGPIOin2::Thermostat) {
        _drawBitmap(Column1 + 13, Line2-2, TimerIconInfo);
        const char* modeStr = "No";
        switch(_ExtHold) {
          case 60000: modeStr = "1m"; break;
          case 120000: modeStr = "2m"; break;
          case 300000: modeStr = "5m"; break;
          case 600000: modeStr = "10m"; break;
          case 900000: modeStr = "15m"; break;
          case 1200000: modeStr = "20m"; break;
          case 1800000: modeStr = "30m"; break;
          case 3600000: modeStr = "1hr"; break;
        }
        _printMenuText(Column1 + 29, Line2, modeStr, _rowSel == 3);
      }
    }
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

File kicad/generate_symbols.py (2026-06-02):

#!/usr/bin/env python3
"""
Generate KiCad 9.0 schematic symbol library for DieselFire.
Uses dataclasses to define symbols, then serializes to KiCad text format.
"""

from dataclasses import dataclass, field
from pathlib import Path
from typing import Optional

BASE = Path(__file__).parent


@dataclass
class Effect:
    font_size: str = "0.8 0.8"
    justify: str = ""

    def serialize(self):
        parts = [f"(size {self.font_size})"]
        if self.justify:
            parts.append(f"(justify {self.justify})")
        return f"(effects (font {parts[0]} {' '.join(parts[1:])}))"


@dataclass
class Text:
    content: str
    at_x: float = 0
    at_y: float = 0
    rotation: float = 0
    font_size: str = "0.8 0.8"
    justify: str = ""

    def serialize(self):
        eff = f"(size {self.font_size})"
        if self.justify:
            eff += f" (justify {self.justify})"
        return f"(text \"{self.content}\" (at {self.at_x} {self.at_y} {self.rotation})\n  (effects {eff}))"


@dataclass
class Property:
    name: str
    value: str
    id: int
    at_x: float = 0
    at_y: float = 0
    rotation: float = 0
    font_size: str = "0.8 0.8"
    justify: str = "left"

    def serialize(self):
        eff = f"(size {self.font_size}) (justify {self.justify})"
        return (f'(property "{self.name}" "{self.value}" (id {self.id}) '
                f"(at {self.at_x} {self.at_y} {self.rotation})\n"
                f"  (effects (font {eff})))")


@dataclass
class Pin:
    name: str
    type: str = "push_thru"  # push_thru, input, output, power_in, passive_linear, etc.
    at_x: float = 0
    at_y: float = 0
    rotation: int = 0
    length: float = 5.08
    uuid: str = ""

    def serialize(self):
        shape = "linear"
        return (f'(pin {self.type} {shape} (at {self.at_x} {self.at_y} {self.rotation}) '
                f"(length {self.length})\n"
                f'  (name "{self.name}" (effects (font (size 0.8 0.8))))\n'
                f'  (uuid "{self.uuid}"))')


@dataclass
class Rect:
    start_x: float
    start_y: float
    end_x: float
    end_y: float
    width: float = 0.254

    def serialize(self):
        return (f'(rect (start {self.start_x} {self.start_y}) (end {self.end_x} {self.end_y})\n'
                f'  (width {self.width}) (fill (color 0 0 0 0)))')


@dataclass
class SymbolBody:
    rect: Rect
    pins: list = field(default_factory=list)

    def serialize(self):
        lines = [self.rect.serialize()]
        for pin in self.pins:
            lines.append(pin.serialize())
        return "\n".join(lines)


@dataclass
class Symbol:
    name: str
    in_bom: bool = True
    on_board: bool = True
    properties: list = field(default_factory=list)
    body: SymbolBody = None

    def serialize(self):
        bom = "yes" if self.in_bom else "no"
        board = "yes" if self.on_board else "no"
        lines = [
            f'(symbol "{self.name}" (in_bom {bom}) (on_board {board})',
        ]
        for prop in self.properties:
            lines.append(prop.serialize())
        lines.append("  (symbol \"" + self.name + "_1\"")
        lines.append("    " + self.body.serialize())
        lines.append("  )")
        lines.append(")")
        return "\n".join(lines)


def make_uuid(n):
    """Generate a deterministic UUID from an integer."""
    hex_str = format(n, '032x')
    return f"{hex_str[:8]}-{hex_str[8:12]}-{hex_str[12:16]}-{hex_str[16:20]}-{hex_str[20:32]}"


def build_esp32_pins():
    """Build ESP32-S3 WROOM pin definitions."""
    pins = []
    # Left side pins (pin number from bottom to top)
    left_pins = [
        ("GPIO43", -17.78), ("GPIO44", -15.24), ("GPIO45", -12.7),
        ("GPIO46", -10.16), ("GPIO47", -7.62), ("GND", -5.08),
        ("3P3", -2.54), ("3P3", 0), ("GND", 2.54), ("GND", 5.08),
        ("GPIO0", 7.62), ("GPIO48", 10.16), ("GPIO49", 12.7), ("GPIO50", 15.24),
    ]
    for i, (name, y) in enumerate(left_pins):
        pins.append(Pin(name, "push_thru", -27.94, y, 0, uuid=make_uuid(1000 + i)))

    # Right side pins
    right_pins = [
        ("GPIO16", -17.78), ("GPIO17", -15.24), ("GPIO18", -12.7),
        ("GPIO19", -10.16), ("GPIO20", -7.62), ("GND", -5.08),
        ("GND", -2.54), ("GND", 0), ("3P3", 2.54), ("3P3", 5.08),
        ("GND", 7.62), ("GND", 10.16), ("GPIO12", 12.7), ("GPIO11", 15.24),
    ]
    for i, (name, y) in enumerate(right_pins):
        pins.append(Pin(name, "push_thru", 27.94, y, 2, uuid=make_uuid(1050 + i)))

    # Top/bottom power pins
    pins.append(Pin("EN", "push_thru", 0, -22.86, 1, uuid=make_uuid(1100)))
    pins.append(Pin("VDD_3P3", "power_in", 0, 22.86, 3, uuid=make_uuid(1101)))
    pins.append(Pin("GND", "power_in", -30.48, 0, 0, uuid=make_uuid(1102)))
    pins.append(Pin("VDD_3P3", "power_in", 30.48, 0, 2, uuid=make_uuid(1103)))
    return pins


def build_buck_pins():
    """Build MP2451 buck converter pins."""
    return [
        Pin("VIN", "push_thru", -10.16, 2.54, 0, uuid=make_uuid(2000)),
        Pin("GND", "push_thru", -10.16, 0, 0, uuid=make_uuid(2001)),
        Pin("SW", "push_thru", -10.16, -2.54, 0, uuid=make_uuid(2002)),
        Pin("FB", "push_thru", 10.16, -2.54, 2, uuid=make_uuid(2003)),
        Pin("EN", "push_thru", 10.16, 0, 2, uuid=make_uuid(2004)),
        Pin("NC", "push_thru", 10.16, 2.54, 2, uuid=make_uuid(2005)),
    ]


def build_ldo_pins():
    """Build AP2112 LDO pins."""
    return [
        Pin("IN", "push_thru", -7.62, 1.27, 0, uuid=make_uuid(3000)),
        Pin("GND", "push_thru", -7.62, -1.27, 0, uuid=make_uuid(3001)),
        Pin("NC", "push_thru", -7.62, -3.81, 0, uuid=make_uuid(3002)),
        Pin("NC", "push_thru", 7.62, -3.81, 2, uuid=make_uuid(3003)),
        Pin("OUT", "push_thru", 7.62, -1.27, 2, uuid=make_uuid(3004)),
    ]


def build_sensor_pins():
    """Build BME280 I2C sensor pins."""
    return [
        Pin("SDI", "push_thru", -7.62, -2.54, 0, uuid=make_uuid(4000)),
        Pin("SCK", "push_thru", -7.62, 0, 0, uuid=make_uuid(4001)),
        Pin("SDO", "push_thru", -7.62, 2.54, 0, uuid=make_uuid(4002)),
        Pin("VDD", "push_thru", 7.62, 2.54, 2, uuid=make_uuid(4003)),
        Pin("GND", "push_thru", 7.62, 0, 2, uuid=make_uuid(4004)),
        Pin("GND", "push_thru", 7.62, -2.54, 2, uuid=make_uuid(4005)),
    ]
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

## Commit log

2026-05-30 Initial commit: DieselFire S3 - ESP32-S3 diesel heater controller
    - KiCad 9.0 PCB project (80x60mm, 2-layer)
    - Schematic with ESP32-S3, power chain, sensors, displays
    - PCB layout with zones, vias, and tracks
    - Custom symbol and footprint libraries
    - ESP32 firmware (PlatformIO/Arduino)
    - Documentation and design files
    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
    [Afterburner-Modern.kicad_pcb, Afterburner-Modern.kicad_sch]
2026-05-30 docs: Add T-Deck integration plan for DieselFire S3
    - Mechanical stackup with T-Deck and DieselFire S3
    - Inter-board communication via I2C + UART
    - Case design specifications (3D printable)
    - Assembly instructions and wiring diagram
    - Firmware integration approach
2026-05-30 docs: Add PCB layout status and completion guide
    - Document current PCB state (zones, vias, test points)
    - Provide component placement guide with positions
    - Instructions for completing layout in KiCad GUI
    - DRC and fabrication steps
2026-05-31 kicad: Complete PCB layout redesign with zone-based placement
    - Rewrite plan.py: zone-based layout (power, MCU, display, sensors, I/O,
    external sensors, expansion) with proper spacing between IC rows
    - Fix apply.py: integer coordinate formatting to match KiCad file format
    - Update critical.py: all route coordinates match new component positions
    - Add autoroute_full.py: pipeline script for autorouting from placed board
    - Fix freerouting path: use external/freerouting-2.2.4-linux-x64/bin/freerouting
    instead of system install
    - Move switches to left edge (SW1 at 10,23; SW2 at 16,23)
    - Group display+touch adjacent (both at x=48) for FPC cable routing
    - Group sensors together (U4, U7 at x=62)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
    [Afterburner-Modern.kicad_pcb]
2026-06-02 Fix PCB DRC violations: increase board to 100mm, remove display mount holes, re-space components
    [Afterburner-Modern.kicad_pcb]
2026-06-02 chore: ignore generated artifacts, KiCad backups, and external tools
    Excludes the 232MB external/ Freerouting download, __pycache__, KiCad
    auto-backups (*-backups/), routing intermediates, scratch DRC/ERC reports,
    the AliExpress reference HTML dump, and scratch -test boards from version
    control.
2026-06-02 kicad: pipeline placement/routing modules and fab-export helpers
    Pending modular pipeline work (placement plan/apply, critical + freerouting
    autoroute, pcb_fab export helpers) plus the project-file and run_pipeline.sh
    updates that drive them.
2026-06-02 feat(kicad): account for ILI9341 display and side buttons across board, case, docs
    Board (pipeline.py):
    - Relocate SW1/SW2 to right-angle (side-actuated) PTS645 tactiles on the front
    edge so they're pressed from the case side, off the display footprint.
    - Add a lid-mounted ILI9341 keepout (module + active area + label) on Dwgs.User.
    - Fixes: fall back to in-memory board when headless LoadBoard returns None;
    set PCB_SHAPE/PCB_TEXT layers after Add (were serialized as UNDEFINED, which
    made boards unloadable); honest run_drc on load failure; runtime probe for
    ZONE_FILLER so GND zones fill where supported and are left defined-unfilled
    (fill in KiCad) where the headless filler would cra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
    [Afterburner-Modern-B_Courtyard.gbr, Afterburner-Modern-B_Cu.gbl, Afterburner-Modern-B_Fab.gbr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]
2026-06-02 Hard fork: rebrand Afterburner to DieselFire
    Complete rename across all layers:
    - Afterburner.cpp -> main.cpp
    - AB/BTC prefixed sources -> DF prefix (DFConfig, DFWifi, DFWebServer, DFota, DF_JSON, DF_GPIO, DFTelnetSpy, DFpreferences, DFDateTime, DFMQTT)
    - KiCad: Afterburner-Modern.* -> DieselFire.*, Afterburner lib -> DieselFire lib
    - All header guards, class names, include paths, string literals updated
    - FOTA URLs: afterburner.mrjones.id.au -> dieselfire.wabo.cc
    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
    [Afterburner-Modern.kicad_pcb, Afterburner-Modern.kicad_sch, DFpartition.csv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]
2026-06-02 firmware: establish DieselFire foundation (ESP32-S3, LVGL-ready, new pins)
    - Create boards/dieselfire.json (ESP32-S3, 8MB flash + PSRAM)
    - Create 8MB_partition.csv (larger app slots + 2MB SPIFFS)
    - Rewrite platformio.ini: dieselfire target with PSRAM + lib_deps,
    keep esp32dev target for legacy OLED hardware
    - Rewrite src/cfg/pins.h for new PCB: ILI9341 SPI display (IO16-18),
    GT911 touch I2C (IO10/21), Blue Wire UART (IO43/44), BME280+DS3231
    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
    [8MB_partition.csv]
2026-06-03 firmware: fix ESP32-S3 compilation, add stubs, update WiFiManager
    - Fix pins.h: use raw uint8_t pin numbers (avoid gpio_num_t enum issues)
    - Fix DFWebServer.cpp: guard HTTPS code behind USE_HTTPS, forward-declare types
    - Fix main.cpp: guard GPIO setup and OLED refs behind USE_ILI9341_DISPLAY
    - Fix BrowserUpload.h: add USE_HTTPS guard for HTTPResponse.hpp dependency
    - Add DFWebServer-stub.cpp: stubs for legacy functions on new target
    - Update platformio.ini: exclude OLED/DF_GPIO/DFWebServer from dieselfire build
    - Add lv_conf.h: minimal LVGL configuration
    - Replace vendored WiFiManager-dev with PIO registry tzapu/WiFiManager@^2.0.17
    - Fix TelnetSpy: cast Serial for ESP32-S3 USB CDC
    - Update i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
    [main.cpp, pins.h]
2026-06-03 display: implement LVGL subsystem with LovyanGFX (ILI9341 + GT911)
    - Replace TFT_eSPI with LovyanGFX v1.1.6 (ESP32-S3 optimized, DMA support)
    - Create ILI9341Driver: LovyanGFX panel, SPI bus, PWM backlight, GT911 touch config
    - Create LVGLDisplay: LVGL 9.5 bindings with PSRAM buffers and flush/touch callbacks
    - Remove custom GT911Touch driver (LovyanGFX has native GT911 support)
    - Wire display.init() in main.cpp setup(), taskHandler() in loop()
    - Delete User_Setup.h (no longer needed with LovyanGFX)
    [ILI9341Driver.cpp, main.cpp]
2026-06-03 screens: Phase 1 - DieselScreen base + MainStatusScreen with LVGL
    - Add DieselScreen base class: dark/amber theme, header bar (clock, BT,
    WiFi, battery, heater state icons), label/bar/led/nav helpers
    - Add MainStatusScreen: 4-tab tabview (Live Telemetry, Big Temp,
    Clock, Fuel/Priming) with 200ms timer-based updates
    - Enable LVGL Montserrat fonts 8-48 in lv_conf.h
    - Update LVGLDisplay to init theme and load MainStatusScreen
    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
2026-06-03 screens: Phase 2 - settings navigation + Thermostat/Frost/Humidity/Timeouts
    - Add SettingsMenuScreen: list-based navigation hub for config screens
    - Add ThermostatScreen: dropdown for method (Standard/Deadband/Linear Hz/
    Ext Contact/Stop-Start), sliders for window size and cyclic temps
    - Add FrostScreen: sliders for auto-on temperature and auto-off rise
    - Add HumidityScreen: slider for BME280 humidity trigger threshold
    - Add TimeoutsScreen: sliders for display dim timeout and menu timeout
    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
2026-06-03 simulator: PC LVGL simulator with SDL2, mock data, and Phase 1-2 screens
    - CMakeLists.txt: Fetch LVGL 9.5, link SDL2, compile screens + mocks
    - lv_conf.h: 32-bit color, Montserrat fonts 8-48, no Helium ASM
    - mock/: heater state machine (30s cycle through all states),
    in-memory NVstore, clock stub, extern globals for screens
    - screens/: copied from src/Display/Screens/ with modified includes
    (../../ → mock include path)
    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
2026-06-03 simulator: fix blank screen and 100% CPU
    - Change LV_DISPLAY_RENDER_MODE_PARTIAL → DIRECT (full frame render)
    - Replace rectangle-copy flush with full memcpy (no byte swapping needed,
    LVGL BGRA == SDL ARGB8888 on little-endian)
    - Add lv_refr_now(display) after screen load (force initial render)
    - Fix timing: remove 5ms threshold, always call lv_tick_inc with delta
    - Cap frame rate at ~60fps (SDL_Delay(16 - elapsed))
    - Add debug printf for startup diagnostics
    - Update SDL2_LIBRARY path to use system library
    [main.cpp]
2026-06-03 simulator: fix LVGL fetch to patch out Helium ASM before build
    - Split FetchContent: Populate() then patch source then add_subdirectory
    - Remove lv_blend_helium.S before CMake processes LVGL build
    (ARM Helium SIMD assembly is incompatible with x86-64 assembler)
    - Remove stale CMAKE_ASM_COMPILER override (no longer needed)
    - Add build verification target check
2026-06-03 simulator: add test pattern, debug logging, fix LVGL display setup
    - Show color gradient test pattern before LVGL init to verify SDL works
    - Set lv_display_set_default() to activate the display
    - Change to LV_DISPLAY_RENDER_MODE_FULL for simpler buffer handling
    - Use sizeof(lv_color_t) for buffer size instead of hardcoded 4
    - Add flush count and delta logging every 2 seconds
    - Print flush count before/after lv_refr_now for diagnostics
    [main.cpp]
2026-06-03 simulator: fix init order - create display before theme init
    - Move DieselScreen::initTheme() after lv_display_create() + set_default()
    - lv_theme_default_init() requires a valid display handle
    - Previous order caused hang/blank screen because theme init had no display
    [main.cpp]
2026-06-03 simulator: fix lv_conf.h path (LV_BUILD_CONF_PATH), add diagnostic output
    - Use correct CMake variable LV_BUILD_CONF_PATH (not LV_CONF_PATH)
    so LVGL finds the simulator's lv_conf.h (not the project root's)
    - Add step-by-step diagnostic prints for display creation
    - Fall back to PARTIAL render mode if needed
    - Disable ThorVG to avoid potential init complications
    [main.cpp]
2026-06-03 simulator: fix pixel stride - use lv_color32_t (4 bytes) for SDL buffer
    - Buffer size was 307200 (correct), but memcpy used sizeof(uint32_t)=4
    while LVGL produces lv_color32_t data (4 bytes/pixel) — this was correct
    - BUT sizeof(lv_color_t)=3 caused confusion; explicitly use sizeof(lv_color32_t)
    for all buffer calculations and row strides
    - Switch back to LV_DISPLAY_RENDER_MODE_FULL for single-pass rendering
    - Add LV_COLOR_DEPTH diagnostic print at startup
    [main.cpp]
2026-06-03 simulator: add SDL direct draw test after LVGL render
    - Show solid red/blue split screen after LVGL init to verify
    SDL still works after LVGL sets up its buffers
    - Replace complex test screen with simple amber background +
    white labels (minimal LVGL rendering test)
    [main.cpp]
2026-06-03 simulator: DIRECT mode — LVGL renders into shared SDL buffer
    - Use LV_DISPLAY_RENDER_MODE_DIRECT with a single framebuffer
    - LVGL renders directly into the buffer, flush callback presents it
    to SDL with zero copying and no intermediate sdl_buf
    - Eliminates pixel stride, format conversion, and buffer size issues
    - Remove all diagnostic code and test patterns
    - MainStatusScreen loads directly (no test screens)
    [main.cpp]
2026-06-03 simulator: fix screen creation - use NULL parent for screen objects
    - DieselScreen constructor was creating screens as children of
    lv_screen_active() instead of as standalone screen objects (NULL parent)
    - This caused LVGL to render the screen background but skip all children
    (tabview, header, labels, etc.) since they were on a non-screen object
    - Fix both simulator/screens/ and src/Display/Screens/ copies
    - Clean up main.cpp: remove all diagnostics, keep DIRECT mode + shared FB
    - Add lv_obj_set_size() call to ensure the screen fills the display
    [main.cpp]
2026-06-03 screens: Phase 3 - timer screens (chart + edit)
    - TimerChartScreen: scrollable list of 14 timers showing DOW matrix,
    time range, repeat flag, and temperature per timer
    - TimerEditScreen: full timer editor with roller pickers for start/stop
    hour and minute, DOW toggle buttons (Sun-Sat), repeat switch,
    temperature slider with live updates
    - Mock NVStorage: add getTimerInfo/setTimerInfo with 14-slot storage
    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
2026-06-03 screens: Phase 4 - WiFi, MQTT, Bluetooth status screens
    - WiFiScreen: shows mode, IP, RSSI, OTA status with 2s timer updates
    - MQTTScreen: shows connection status, QoS, topic prefix
    - BTScreen: shows BLE status, MAC address, type info
    - SettingsMenu: add network screens to top of settings list
    - Fix lv_timer_get_user_data in WiFiScreen lambda
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2026-06-03 screens: Phase 7 - system utility screens
    - SystemScreen: firmware version, board revision, WiFi/menu mode
    - RebootScreen: countdown display with timer (10-0)
    - PasswordScreen: 4-digit PIN entry with numeric keypad (1688)
    - HourMeterScreen: run/glow/uptime hour display
    - InheritScreen: OEM controller settings import instructions
    - All screens added to SettingsMenu
2026-06-03 fix: add header bar with settings gear to MainStatusScreen
    - MainStatusScreen::onLoad() was missing the createHeader() call
    - The gear icon (settings) and all header icons (clock, BT, WiFi,
    battery, heater) now appear on the main telemetry screen
    - Tabview positioned at y=22 leaves room for the 22px header bar
2026-06-03 fix: settings menu item visibility and layout
    - Set explicit button height (32px) and padding for list items
    - Set label text color to white on both button and child label
    - Remove button borders for cleaner appearance
2026-06-03 fix: replace header icons with proper buttons for reliable click handling
    - Back arrow changed from label to lv_button (36x20px) with "← Back" text
    - Settings gear changed from label to lv_button (36x20px)
    - Both buttons have hover/active state styling
    - Adds createContentArea() helper for scrollable content below header
2026-06-03 fix: simplify header - back arrow, clock, settings gear only
    - Remove BT/WiFi/battery/heater status icons from header (reduces clutter)
    - Back arrow and settings gear are clickable labels with explicit size
    - Use std::function callback for back navigation instead of _returnScreen
    pointer (avoids stale object references)
    - SettingsMenuScreen sets a lambda callback on target screens
2026-06-03 fix: clean up sub-screens on navigation to prevent memory exhaustion
    - SettingsMenuScreen now tracks _subScreen and deletes it before opening
    a new one (prevents LVGL memory pool exhaustion after N navigations)
    - Back callback: deletes sub-screen's LVGL object and C++ object after
    restoring the settings menu screen
    - Fix header spacing: increase back arrow and settings gear to 22x22px,
    position at x=4 and x=TFT_WIDTH-24 respectively
2026-06-03 fix: restore header icons, add settings back navigation, scrollable timer
    - Restore BT/WiFi/battery/heater status icons in header bar with
    compact spacing (14px each, right-aligned between clock and gear)
    - Restore updateHeader* methods from no-ops to properly update icons
    - SettingsMenuScreen: remove hideBackButton, add onBack() that creates
    a fresh MainStatusScreen (back arrow returns to main screen)
    - TimerEditScreen: use scrollable content area (createContentArea)
    with reduced spacing for better fit
2026-06-03 fix: TimerEditScreen layout - explicit roller heights, compact spacing
    - Rollers now have explicit 44px height (prevents overlap from defaults)
    - Use makeRoller helper for consistent roller creation
    - Reorganized into rows with LINE_H=34 spacing between rows
    - DOW buttons shrunk to 30x24px with 34px pitch
    - Content area scrollable when content exceeds visible height
2026-06-03 feat: Home Assistant MQTT autodiscovery + climate integration
    - sMQTTparams: add haDiscovery flag (default on, stored as haDisc in NVS)
    - HADiscovery: publish discovery configs on MQTT connect for 3 entities:
    - Climate entity (off/heat/auto modes, eco/none/boost presets)
    - 8 sensor entities (heat exchanger temp, run state, error, fuel, fan, voltage, pump)
    - 2 binary sensors (running, has_error)
    - Publish HA state topics on each blue wire cycle:
    - climate/mode: off when stopped, heat/auto when running
    - climate/action: off/heating/idle/fan based on RunState
    - climate/temperature: current setpoint from CDemandManager
    - climate/current_temperature: from primary temp sensor
    - cli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
2026-06-03 feat: re-implement DFWebServer with ESPAsyncWebServer
    Replaces the removed fhessel/esp32_https_server library dependency with
    me-no-dev/ESPAsyncWebServer, which uses the already-vendored AsyncTCP.
    New implementation (src/WiFi/DFWebServer.cpp, ~300 lines vs 1841):
    - AsyncWebServer on port 80 with WebSocket support
    - Routes: / (SPIFFS), /update (OTA upload), /reboot, /formatspiffs,
    /wmconfig, /resetwifi, 404 with SPIFFS listing
    - WebSocket / for JSON telemetry (sendWebSocketString)
    - WebSocket /update for OTA progress + file management (erase/rename)
    - OTA upload via ESPAsyncWebServer native upload callback
    (supports .bin firmware + SPIFFS content files)
    - Inline HTML page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
2026-06-03 feat: FOTA release pipeline and version bump
    Release pipeline:
    - .github/workflows/release.yml: GitHub Actions workflow triggered
    on tag push (v*), builds dieselfire firmware, generates fota.json
    manifest, creates GitHub Release with binary + manifest
    - scripts/gen_fota_json.py: converts semver tag (e.g. v3.3.0) to
    the integer format esp32FOTA expects (e.g. 3300)
    Firmware version:
    - Bumped to V3.3 (FirmwareRevision=33, FirmwareSubRevision=0)
    - Changed FirmwareDate from hardcoded string to __DATE__ macro
    (auto-generates from build date)
    The add_CRC.py post-build action now correctly appends MODBUS CRC-16
    to firmware.bin (CRC over entire file = 0x0000, size mod 4 = 2)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
    [main.cpp]
2026-06-03 feat: Blue Wire protocol edge case tests + fix double-TX bug
    Bug fix:
    - SimTxMgr::Start() was writing the frame to VirtualSerial, but it is
    called from both Idle and TxStart states, causing a double-write.
    Fixed by moving the serial write to CheckTx() only (matches original
    CTxManage behavior where the HW timer ISR triggers the write).
    Tests (simulator/test_bluewire.cpp, all 9 pass):
    1. Normal exchange completes without crash
    2. Bad CRC triggers ExchangeComplete and recovers
    3. Partial frame triggers timeout and recovers
    4. No response triggers timeout and recovers
    5. Rogue bytes after valid frame are dumped
    6. Slow response (40ms) stays within 50ms timeout
    7. Ve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
2026-06-03 feat: MQ-7 CO sensor driver + clean up redundant BME280
    - src/Utility/MQCOSensor.h/cpp: MQ-7 CO gas sensor driver
    - ADC1_CHANNEL_3 (GPIO4) 12-bit reading with EMA filter
    - Voltage divider correction (10k+10k = 2:1 ratio)
    - Rs/R0 ratio using sensor circuit model (Vc=5V, Rl=10k)
    - CO concentration via log-log sensitivity curve
    (log10(PPM) = -0.73 + -2.76 * log10(Rs/R0))
    - Digital alarm threshold (GPIO5, active-low)
    - Calibration: stores R0 for clean-air reference
    - Guarded by USE_MQ7 flag (DFConfig.h)
    Changes:
    - src/cfg/pins.h: added MQ7_AOUT = GPIO4
    - src/main.cpp: removed redundant Adafruit_BME280 bme global
    (CTempSense already manages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
    [MQCOSensor.cpp, main.cpp, pins.h]
2026-06-03 feat: cooperative Blue Wire simulator + WASM build target
    Complete rewrite from threaded to cooperative (single-threaded) model:
    All three threads (main + BlueWire task + heater emulator) collapsed into
    a single main loop — runs identically on native Linux and in browser WASM.
    Key changes:
    - FreeRTOS.h: removed std::thread, mutex, condition_variable; queues
    and semaphores are now simple lock-free wrappers around std::queue
    and bool flags
    - vserial.h/.cpp: replaced socketpair + ioctl with in-process ring
    buffer (heap-allocated, pre-allocated at construction). Solves the
    extern-reference-vs-value ODR violation bug that caused valgrind errors
    - heater_emu.h/.cpp: run()/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
    [main.cpp]
2026-06-03 chore: fix gitignore — keep test_bluewire.cpp
2026-06-03 chore: pre-public cleanup — remove artifacts, fix branding, add alpha disclaimer
    Cleanup before making repo public:
    Removed tracked artifacts:
    - Bootload/ (Afterburner firmware binaries, Windows exes, bootloader archives)
    - Arduino/Afterburner/ (old Arduino IDE project)
    - kicad/Afterburner-Modern* (old KiCad project)
    - kicad/fabrication/ (generated PCB outputs: gerbers, CPL, pick-and-place)
    - kicad/test_* ERC/DRC reports
    - Afterburner-Modern-drc.{json,rpt} at repo root
    - fota.json (generated artifact, already in .gitignore)
    Branding fixes:
    - BTC -> DieselFire/DF in debug strings (main.cpp, Protocol.cpp, BlueWireTask.cpp)
    - BTCWifi.h -> DFWifi.h in 7 OLED includes
    - BT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
    [Afterburner-Modern.drl, DieselFire-B_Courtyard.gbr, DieselFire-B_Cu.gbl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]
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2026-06-03 fix: WASM build — DebugPort.h needs EMSCRIPTEN guard, WiFi.h duplicate typedef
    - DebugPort.h: TelnetSpy include path now also guarded for __EMSCRIPTEN__
    (previously only __linux__, but Emscripten doesn't define __linux__)
    - WiFi.h mock: removed duplicate typedef int arduino_event_t that conflicted
    with the struct definition on line 44
2026-06-03 fix: WASM build - SensorScreen hex escape sequence overflow
    Emscripten's emcc treats out-of-range hex escape sequences (\xB0C parsed as
    \x0B0C, exceeds char range) as errors. Fixed by using a static const for
    the degree-Celsius suffix string.
2026-06-03 fix: WASM deploy — add contents:write permission, explicit git user
2026-06-03 fix: fix hex escape in real SensorScreen (same bug as sim copy)
2026-06-03 fix: Pages deploy — add cname parameter so CNAME isn't wiped
2026-06-03 fix: switch to native actions/deploy-pages for WASM deployment
    The legacy Pages builder fails on .wasm/.js output. Switch to the native
    GitHub Actions Pages deployment (actions/upload-pages-artifact +
    actions/deploy-pages) which bypasses the legacy builder entirely.
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2026-06-04 fix: correct file move order — move WASM to sim/ first, then copy landing
2026-06-04 fix: critical UI gaps — heater ON/OFF, temp control, fuel prime, reboot
    - MainStatusScreen: added START/STOP button on Data tab that calls
    requestOn()/requestOff(). Button switches color orange/red based on
    heater state. Fuel tab: PRIME/STOP toggle + RESET fuel gauge buttons.
    Temp tab: +/- setpoint controls calling CDemandManager::deltaDemand().
    - RebootScreen: now calls ESP.restart() when countdown reaches zero
    (was decrementing past zero forever).
    - MQTTScreen: replaced hardcoded placeholder strings with live reads
    from NVstore (host, port, prefix, status, HA discovery flag) via a
    2-second timer.
    - Simulator mocks: added functional CDemandManager (deltaDemand, _degC
    storage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
2026-06-04 fix: remove deprecated src_filter, fix unknown upload_protocol
    - Rename src_filter → build_src_filter to fix PlatformIO deprecation
    - Remove upload_protocol (was using unrecognized 'esp_usb_cdc')
    - Let PlatformIO use default esptool protocol (correct for ESP32-S3)

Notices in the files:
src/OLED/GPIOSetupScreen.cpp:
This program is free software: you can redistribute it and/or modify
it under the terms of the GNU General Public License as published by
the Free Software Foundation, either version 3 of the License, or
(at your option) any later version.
